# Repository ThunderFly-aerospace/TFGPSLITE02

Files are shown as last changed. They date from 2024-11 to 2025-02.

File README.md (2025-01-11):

# TFGPSLITE02 - Compact GNSS Module for Lightweight UAVs



The **TFGPSLITE02** module is a compact GNSS solution based on the [u-blox SAM-M8Q](https://www.u-blox.com/en/product/sam-m8q-module). It is designed for small, lightweight, and simple UAVs, offering excellent positioning accuracy with support for multiple satellite constellations. It connects seamlessly to flight controllers via the [Pixhawk standard "Basic GPS Port"](https://github.com/pixhawk/Pixhawk-Standards/blob/master/DS-009%20Pixhawk%20Connector%20Standard.pdf).

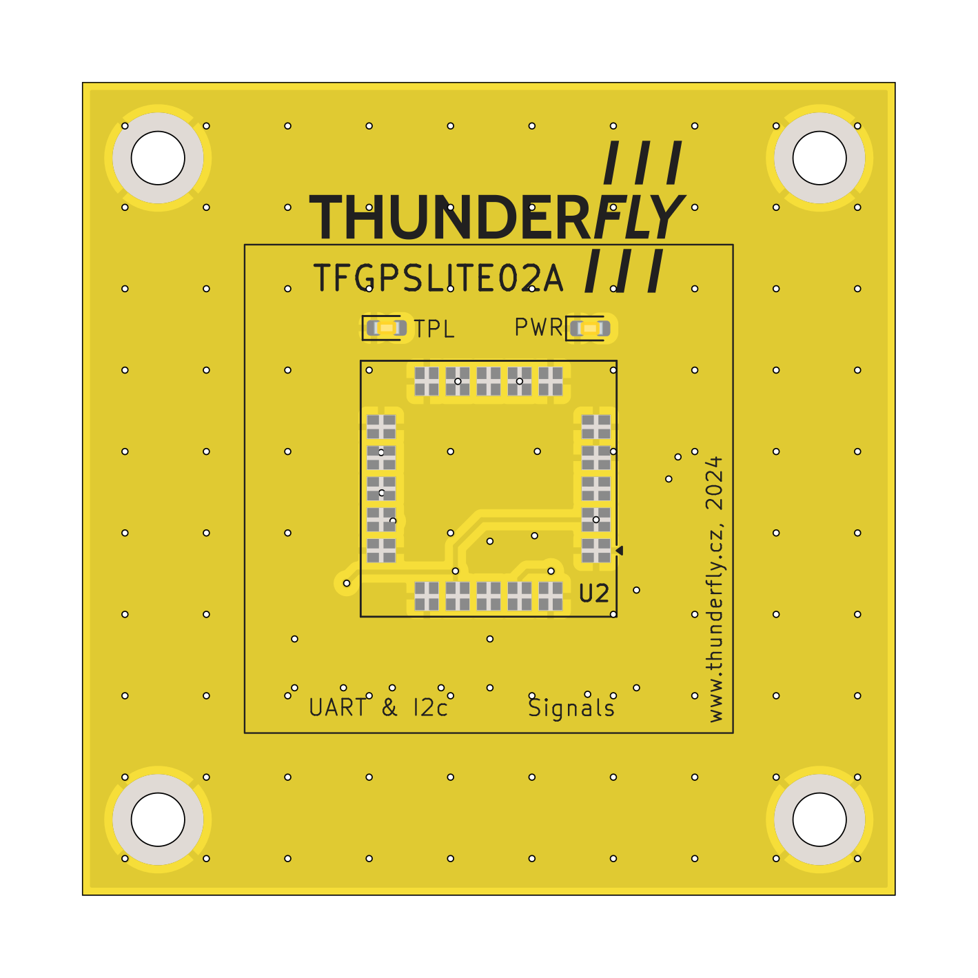
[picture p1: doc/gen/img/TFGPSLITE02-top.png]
TFGPSLITE02 top view


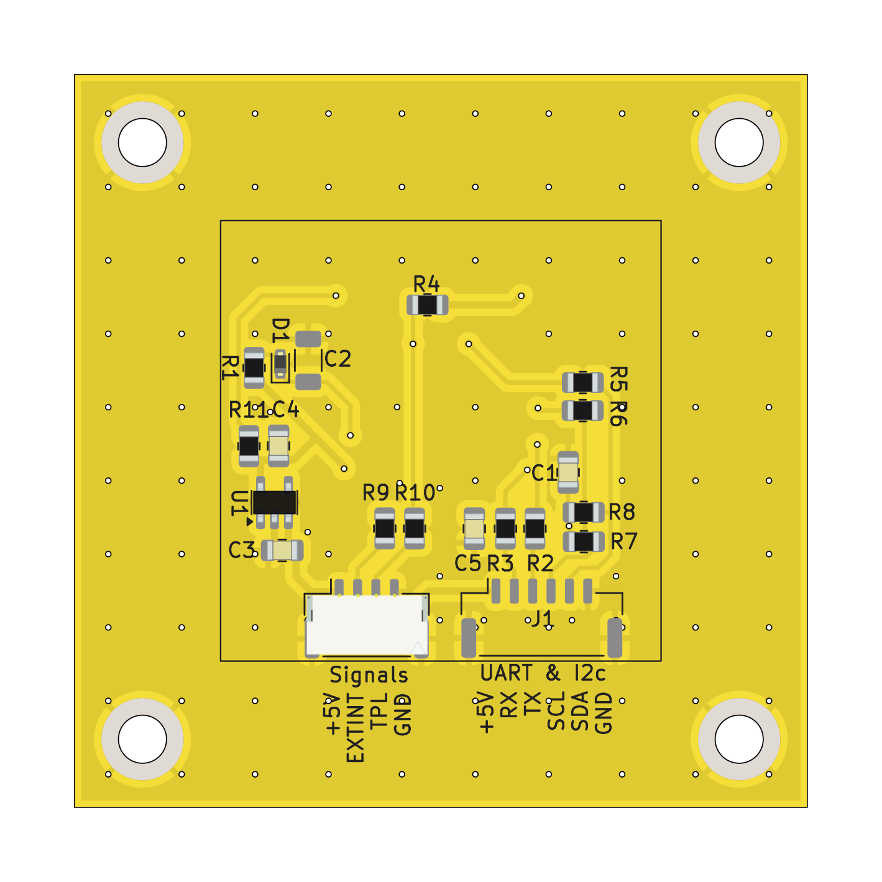
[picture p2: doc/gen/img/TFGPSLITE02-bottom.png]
TFGPSLITE02 bottom view


## Features

- **GNSS Support**: Concurrent reception of up to three GNSS systems (GPS, Galileo, GLONASS).
- **Compact Design**: Compact flat form factor with integrated patch antenna.
- **High Sensitivity**: Superior performance in environments with weak or obstructed GNSS signals.
- **Augmentation Systems**: Support for SBAS (WAAS, EGNOS, MSAS, GAGAN) and QZSS.
- **Advanced Security**:
  - Geofencing for operational boundaries.
  - Spoofing detection to enhance signal integrity.
  - Message integrity protection.
- **Wide Operational Range**:
  - Altitude: Up to 50,000 m.
  - Velocity: Up to 500 m/s.
  - Dynamic tolerance: Up to 4 g.
- **Built-in RTC**: Ensures faster Time-To-First-Fix (TTFF) after prolonged power-off periods.

## Technical Specifications

- **Interfaces**:
  - UART and I2C (via Basic GPS Port).
  - Time pulse output (1 PPS, configurable up to 10 MHz).
- **Power Supply**:
  - Main supply voltage: 5 V.
  - Typical current consumption is 30 mA.
- **GNSS Performance**:
  - Cold start TTFF: 26 s (GPS).
  - Hot start TTFF: 1 s.
  - Horizontal position accuracy: 2.5 m CEP.
- **Environmental Tolerances**:
  - Operating temperature: -40 °C to 85 °C.
  - Storage temperature: -40 °C to 85 °C.
- **Physical properties**: 
  - Dimensions 50x50x8mm
  - Weight 11.3 grams

## Connection to Flight Controller

The module interfaces with flight controllers using the Pixhawk standard **Basic GPS Port**. The port pinout is as follows:

| Pin | Signal | Voltage |
|-----|---|---|
| 1 | VCC | +5V |
| 2 | TX (OUT)  | +3.3V |
| 3 | RX (IN) | +3.3V |
| 4 | I2C SCL | +3.3V |
| 5 | I2C SDA | +3.3V |
| 6 | GND | GND |

## Connection to payload

The module interfaces with the payload with the following signals:

| Pin | Signal | Voltage |
|-----|---|---|
| 1 | VCC | +5V |
| 2 | EXTINT (IN)  | +3.3V |
| 3 | TPL (OUT) | +3.3V |
| 4 | GND | GND |

## Where to get it?

The TFGPSLITE02 is commercially available from [ThunderFly s.r.o.](https://www.thunderfly.cz/). For a commercial quotation, contact us by email at sale@thunderfly.cz or shop at our [Tindie store](https://www.tindie.com/stores/thunderfly/).

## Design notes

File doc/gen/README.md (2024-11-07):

# PCB

Board size: 50.0x50.0 mm (1.97x1.97 inches)

- This is the size of the rectangle that contains the board
- Thickness: 1.6 mm (63 mils)
- Material: FR4
- Finish: None
- Layers: 2
- Copper thickness: 35 µm

Solder mask: TOP / BOTTOM

- Color: Green

Silk screen: TOP / BOTTOM

- Color: White

Stackup:

| Name | Type | Color | Thickness [µm]| Material | Er | Loss tan |
|---|---|---|---|---|---|---|
| F.SilkS | Top Silk Screen | | | | | |
| F.Paste | Top Solder Paste | | | | | |
| F.Mask | Top Solder Mask | | 10 | | | |
| F.Cu | copper | | 35 | | | |
| dielectric 1 | core | | 1510 | FR4 | 4.5 | 0.020 |
| B.Cu | copper | | 35 | | | |
| B.Mask | Bottom Solder Mask | | 10 | | | |
| B.Paste | Bottom Solder Paste  | | | | | |
| B.SilkS | Bottom Silk Screen | | | | | |

# Important sizes

Clearance: 0.2 mm (8 mils)

Track width: 0.3 mm (12 mils)

- By design rules: 0.0 mm (0 mils)

Drill: 0.4 mm (16 mils)

- Vias: 0.4 mm (16 mils) [Design: 0.4 mm (16 mils)]
- Pads: 3.3 mm (130 mils)
- The above values are real drill sizes, they add 0.1 mm (4 mils) to plated holes (PTH)

Via: 0.6/0.3 mm (24/12 mils)

- By design rules: 0.5/0.3 mm (20/12 mils)
- Micro via: yes [0.2/0.1 mm (8/4 mils)]
- Buried/blind via: yes
- Total: 115 (thru: 115 buried/blind: 0 micro: 0)

Outer Annular Ring: 0.1 mm (4 mils)

- By design rules: 1.15 mm (45 mils)

Eurocircuits class: 6C
- Using min drill 0.35 mm for an OAR of 0.13 mm

# General stats

Components count: (SMD/THT)

- Top: 3/0 (SMD)
- Bottom: 20/0 (SMD)

Defined tracks:

- 0.3 mm (12 mils)
- 0.5 mm (20 mils)

Used tracks:

- 0.3 mm (12 mils) (70) defined: yes
- 0.5 mm (20 mils) (34) defined: yes

Defined vias:

Used vias:

- 0.6/0.3 mm (24/12 mils) (Count: 115, Aspect: 2.7 A) defined: no

Holes (excluding vias):

- 3.2 mm (126 mils) (4)

Oval holes:

Drill tools (including vias and computing adjusts and rounding):

- 0.4 mm (16 mils) (115)
- 3.3 mm (130 mils) (4)

Solder paste stats:

Using a paste with 87.75 % alloy, that has an specific gravity for the alloy of 7.4 g/cm³
and 1.0 g/cm³ for the flux. This paste has an specific gravity of  4.15 g/cm³.

The stencil thickness is  0.12 mm.

| Side | Pads with paste | Area [mm²] | Paste [g] |
|---|---|---|---|
| Top | 84 | 36.55 | 0.18 |
| Bottom | 53 | 70.45 | 0.35 |
| Total  | 137 | 107.01 | 0.53 |

Note: this is just an approximation to the theoretical value. Margins of the solder mask and waste aren't computed.

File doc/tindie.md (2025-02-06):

# TFGPSLITE02 - Compact GNSS Module for UAVs

A lightweight GNSS module with a high-quality ground plane, ideal for UAVs, multirotors, planes, and balloons.

The TFGPSLITE02 is a compact and lightweight open-source hardware GNSS module based on the u-blox SAM-M8Q receiver. Designed for small UAVs and simple navigation applications, it offers precise positioning with support for GPS, Galileo, and GLONASS constellations.

One of its key advantages is the high-quality integrated ground plane, which enhances signal reception and reduces interference. Unlike lower-cost solutions where supporting components are placed next to the antenna, degrading signal integrity, this module employs a carefully designed layout that separates supporting circuitry. By positioning these components on the opposite side of the board, this design choice, while increasing manufacturing costs, significantly improves signal stability and accuracy—an essential factor for UAV applications where GNSS signal integrity is critical.

With seamless integration via the Pixhawk Basic GPS Port, this module is an excellent choice for developers and hobbyists looking for a simple yet effective GNSS solution.

## Open-Source & Customizable

The TFGPSLITE02 is open-source hardware, allowing engineers, developers, and UAV enthusiasts to modify, improve, and adapt the design to their specific needs. Design files, schematics, and firmware resources are publicly available in the project’s repository.

---

## Key Features
- **Multi-GNSS Support** – Receives GPS, Galileo, and GLONASS signals for increased accuracy.
- **Compact and Lightweight** – Weighing only **11.3 grams**, ideal for weight-sensitive UAV applications.
- **High-Quality Ground Plane** – Improved signal reception compared to low-cost GNSS modules.
- **Reliable Performance in Challenging Environments** – Works in areas with weak GNSS signals.
- **Support for SBAS and QZSS** – Enhances positioning accuracy.
- **Advanced Security Features**:
  - Geofencing support
  - Spoofing detection
  - Message integrity protection
- **Built-in RTC (Real-Time Clock)** – Reduces Time-To-First-Fix after power loss.
- **Wide Operating Range**:
  - Up to **50,000m altitude**, **500m/s velocity**, and **4g dynamic tolerance**.

---

## Technical Specifications
- **Receiver**: u-blox SAM-M8Q GNSS module
- **Interfaces**:
  - UART and I2C (via Pixhawk Basic GPS Port)
  - 1PPS time pulse output (configurable up to 10 MHz)
- **Power Requirements**:
  - Voltage: **5V**
  - Typical power consumption: **30mA**
- **Positioning Performance**:
  - Cold start TTFF: **26s** (GPS)
  - Hot start TTFF: **1s**
  - Accuracy: **2.5m CEP**
- **Environmental Ratings**:
  - Operating temperature: **-40°C to +85°C**
  - Storage temperature: **-40°C to +85°C**
- **Physical Dimensions**:
  - **50mm × 50mm × 8mm**
  - **Weight: 11.3g**

---

## Easy Integration with UAV Systems
The TFGPSLITE02 connects to flight controllers via the **Pixhawk Basic GPS Port**, ensuring hassle-free setup. The pinout is:

| Pin | Signal  | Voltage |
|-----|---|---|
| 1 | VCC | 5V |
| 2 | TX (OUT) | 3.3V |
| 3 | RX (IN) | 3.3V |
| 4 | I2C SCL | 3.3V |
| 5 | I2C SDA | 3.3V |
| 6 | GND | GND |

It also supports external payload connections for additional signals.

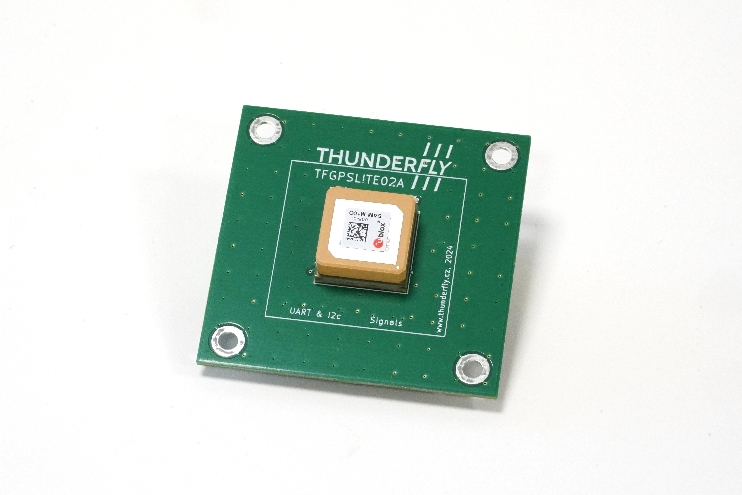
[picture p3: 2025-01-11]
doc/img/TFGPSLITE02_top.jpg

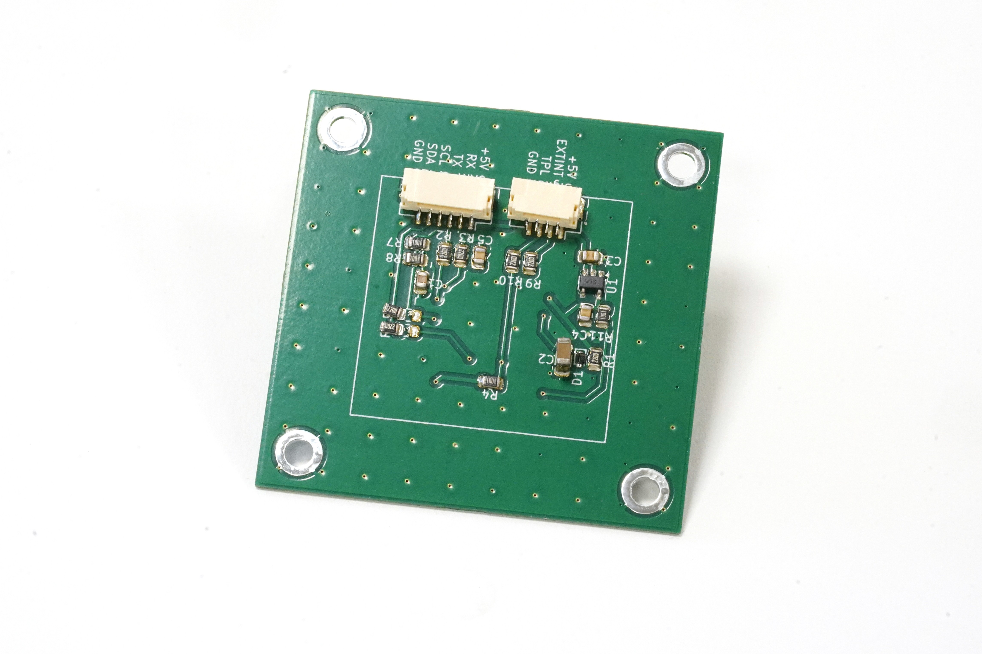
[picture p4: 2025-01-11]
doc/img/TFGPSLITE02_bot.jpg

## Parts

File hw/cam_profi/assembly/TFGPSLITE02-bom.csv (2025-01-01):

Component | Description | Part | References | Value | Footprint | Quantity Per PCB | Datasheet | ust_id | sim.device | sim.pins
1 | Unpolarized capacitor, small symbol | C_Small | C3C4C5 | 100n | C_0805_2012Metric | 3 | ~ | 5c70984812875079b91f8bf2
2 | Unpolarized capacitor, small symbol | C_Small | C1 | 1u | C_0805_2012Metric | 1 | ~ | 5c70984812875079b91f8bc3
3 | Unpolarized capacitor | C | C2 | C | R_1206_3216Metric | 1 | ~
4 | Diode, small symbol | D_Small | D1 | BZX585-B5V6.115 | D_SOD-523 | 1 | ~ |  | D | 1=K 2=A
5 | Light emitting diode, small symbol | LED_Small | D3 | GREEN | LED_0603_1608Metric | 1 | ~ | 60d582331287500165f859d0
6 | Light emitting diode, small symbol | LED_Small | D2 | RED | LED_0603_1608Metric | 1 | ~ | 60d582331287500165f859d0
7 |  | SM04B-GHS-TB | J2 | SM04B-GHS-TB | JST_GH_SM04B-GHS-TB_1x04-1MP_P1.25mm_Horizontal | 1
8 | 1x07 2.54 mm pitch header | SM06B-GHS-TB | J1 | SM06B-GHS-TB | JST_GH_SM06B-GHS-TB_1x06-1MP_P1.25mm_Horizontal | 1
9 | Resistor, small symbol | R_Small | R2R3R5R6R9R10 | 220R | R_0805_2012Metric | 6 | ~ | 5c70984512875079b91f8958
10 | Resistor, small symbol | R_Small | R4R11 | 1k | R_0805_2012Metric | 2 | ~ | 5c70984512875079b91f895c
11 | Resistor, small symbol | R_Small | R1R7R8 | R_Small | R_0805_2012Metric | 3 | ~
12 | 300mA Low-dropout Voltage Regulator, Vout 3.3V, Vin up to 5.5V, SOT-23 | MIC5504-3.3YM5 | U1 | MIC5504-3.3YM5 | SOT-23-5 | 1 | http://ww1.microchip.com/downloads/en/DeviceDoc/MIC550X.pdf | 5c7255e81287500b4e112ea2
13 | GPS ublox M8 variant | SAM-M8Q | U2 | SAM-M8Q | ublox_SAM-M8Q | 1 | https://content.u-blox.com/sites/default/files/documents/SAM-M8Q_DataSheet_UBX-16012619.pdf

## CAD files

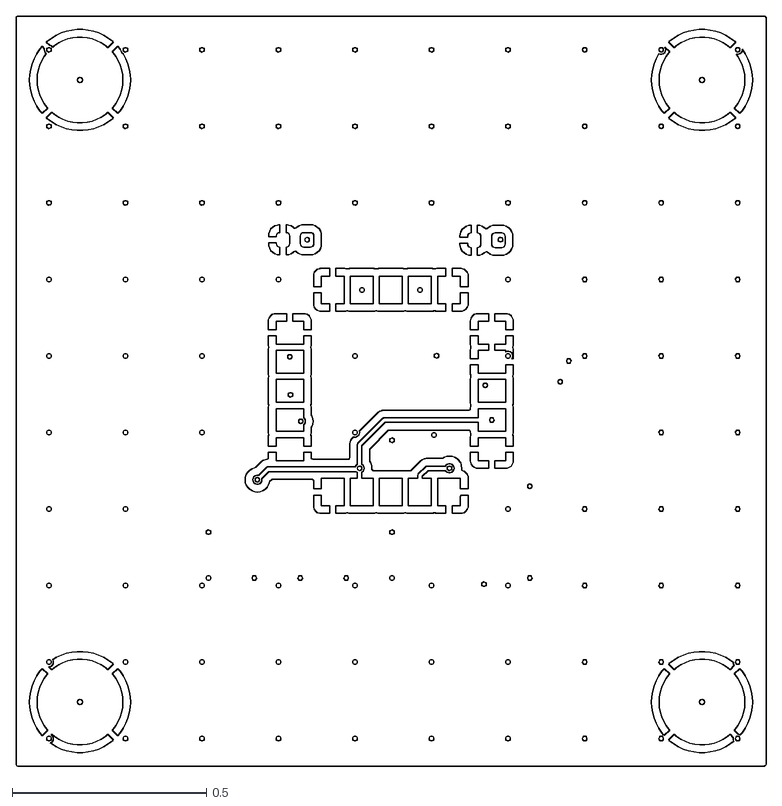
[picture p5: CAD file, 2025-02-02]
doc/gen/dxf/TFGPSLITE02-F_Cu.dxf
1.93 x 1.93

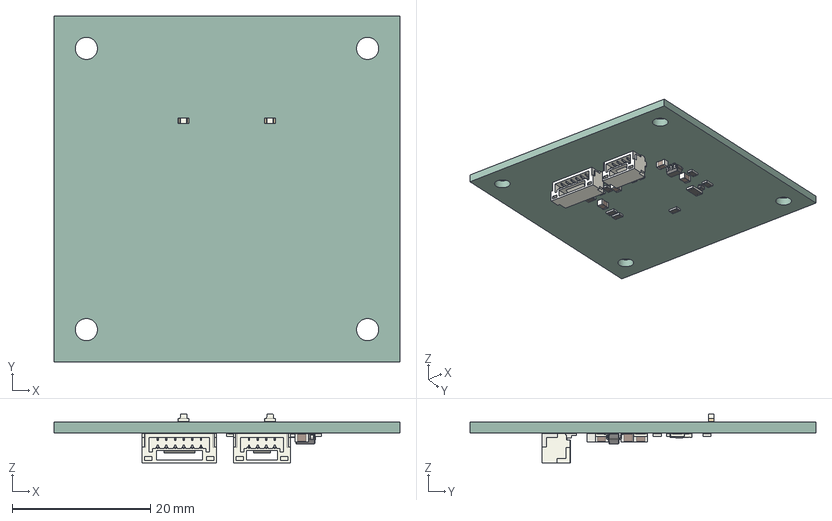
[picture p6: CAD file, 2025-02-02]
doc/gen/TFGPSLITE02.step
50.0 x 50.0 x 7.04 mm
LED_0603_1608Metric x 2
R_0805_2012Metric x 11
C_0805_2012Metric x 4
SOT_23_5
D_SOD_523
JST_SM06B_GHS_TB
JST_SM04B_GHS_TB
R_1206_3216Metric
kibot_6tp2d779_PCB

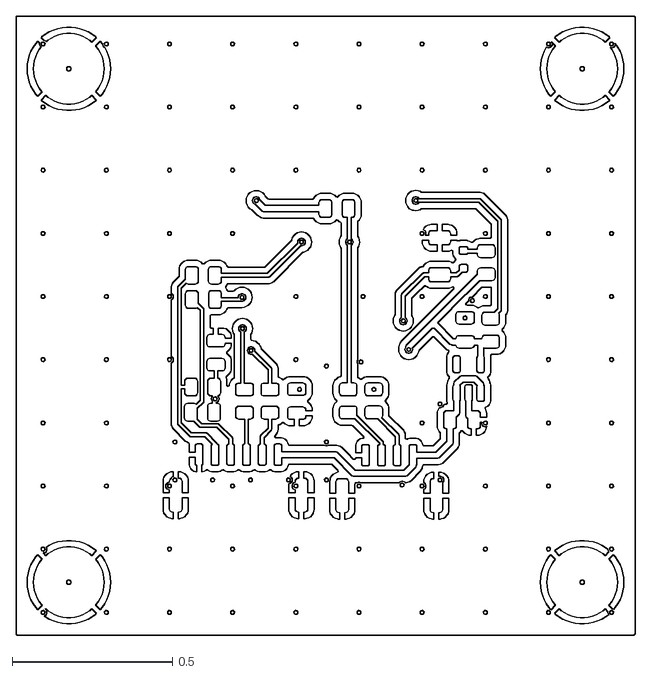
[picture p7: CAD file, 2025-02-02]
doc/gen/dxf/TFGPSLITE02-B_Cu.dxf
1.93 x 1.93

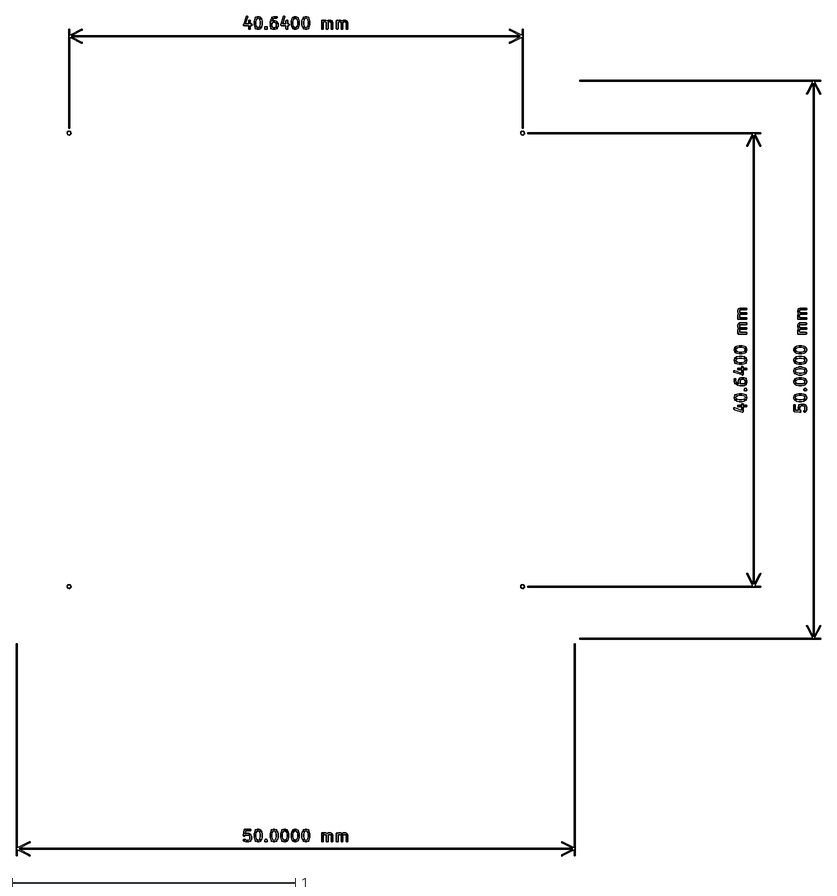
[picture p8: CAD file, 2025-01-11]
doc/gen/dxf/TFGPSLITE02-User_Drawings.dxf
2.84 x 2.96

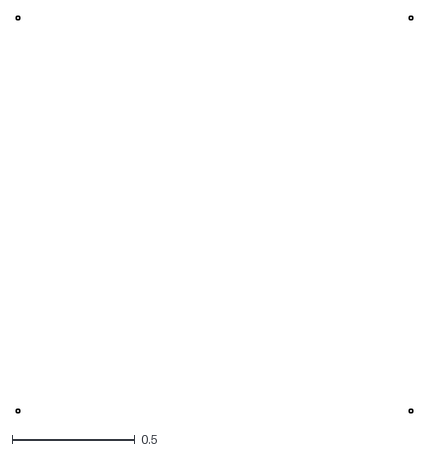
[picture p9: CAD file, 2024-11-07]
doc/gen/dxf/TFGPSLITE02-Margin.dxf
1.61 x 1.61

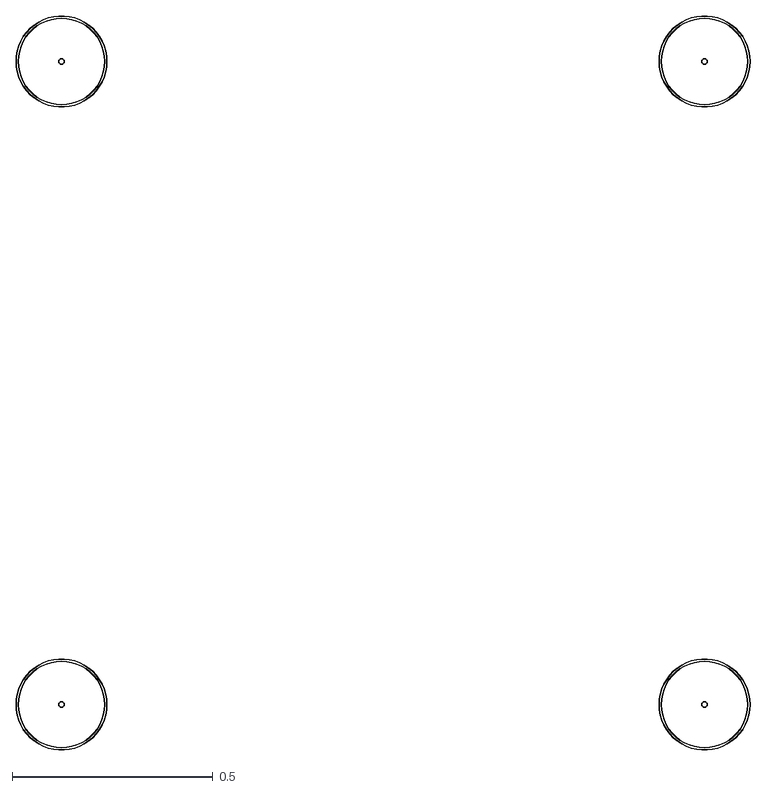
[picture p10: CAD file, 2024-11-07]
doc/gen/dxf/TFGPSLITE02-User_Comments.dxf
1.83 x 1.83

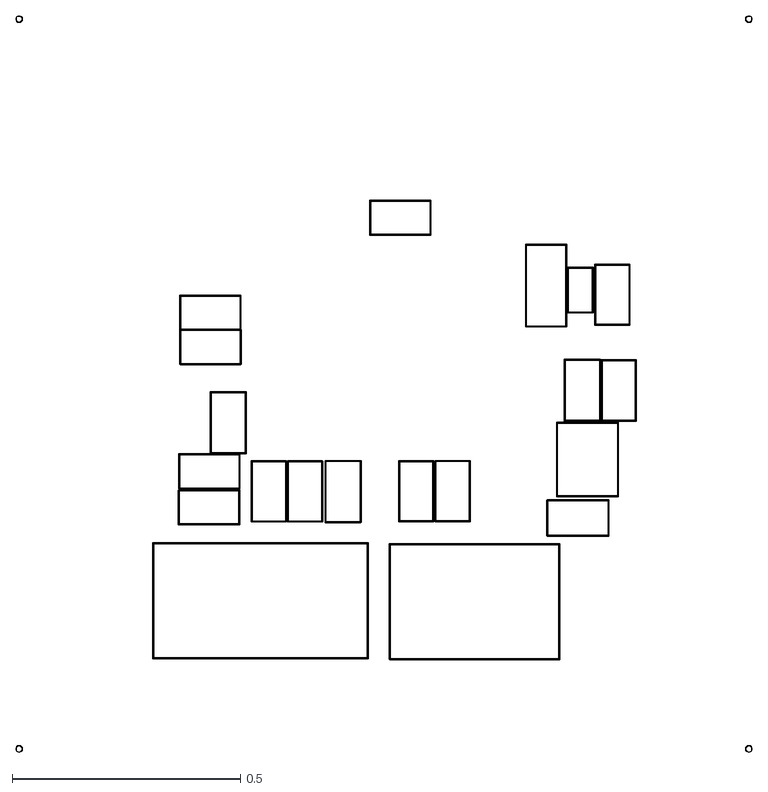
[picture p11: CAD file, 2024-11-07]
doc/gen/dxf/TFGPSLITE02-B_Courtyard.dxf
1.61 x 1.61

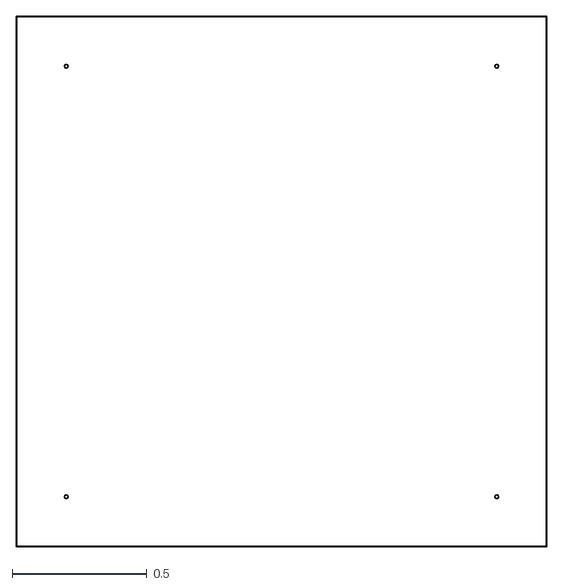
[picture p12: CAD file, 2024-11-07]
doc/gen/dxf/TFGPSLITE02-Edge_Cuts.dxf
1.97 x 1.97

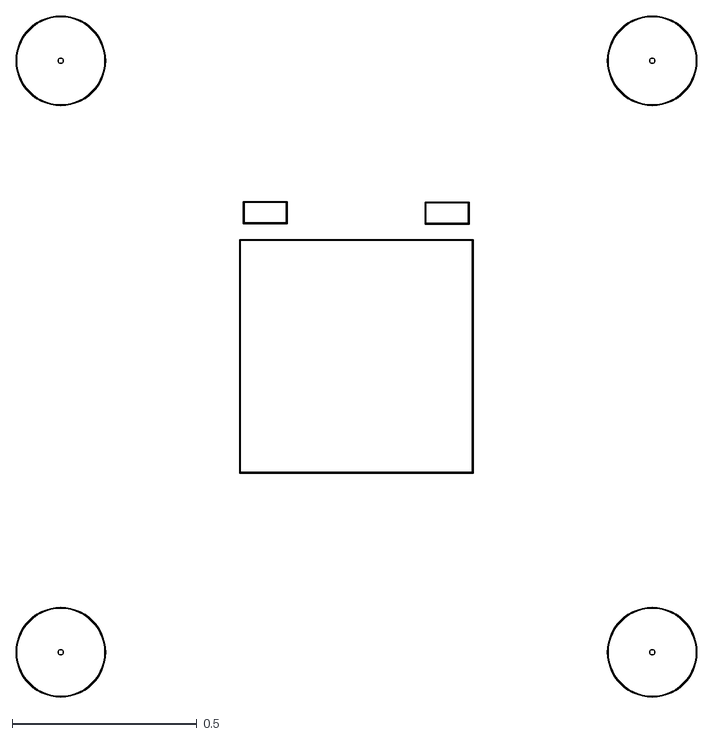
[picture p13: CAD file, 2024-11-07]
doc/gen/dxf/TFGPSLITE02-F_Courtyard.dxf
1.84 x 1.84

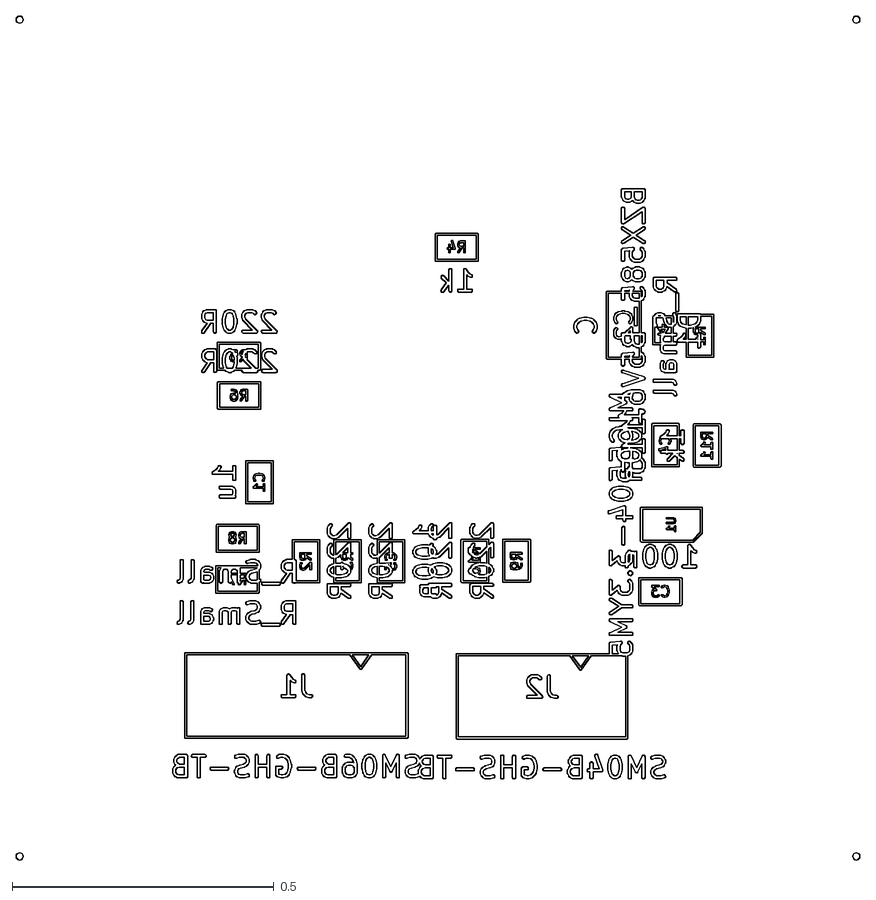
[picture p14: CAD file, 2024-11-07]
doc/gen/dxf/TFGPSLITE02-B_Fab.dxf
1.61 x 1.61

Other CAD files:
doc/gen/dxf/TFGPSLITE02-B_Adhesive.dxf
doc/gen/dxf/TFGPSLITE02-B_Mask.dxf
doc/gen/dxf/TFGPSLITE02-B_Paste.dxf
doc/gen/dxf/TFGPSLITE02-B_Silkscreen.dxf
doc/gen/dxf/TFGPSLITE02-F_Adhesive.dxf
doc/gen/dxf/TFGPSLITE02-F_Fab.dxf
doc/gen/dxf/TFGPSLITE02-F_Mask.dxf
doc/gen/dxf/TFGPSLITE02-F_Paste.dxf
doc/gen/dxf/TFGPSLITE02-F_Silkscreen.dxf

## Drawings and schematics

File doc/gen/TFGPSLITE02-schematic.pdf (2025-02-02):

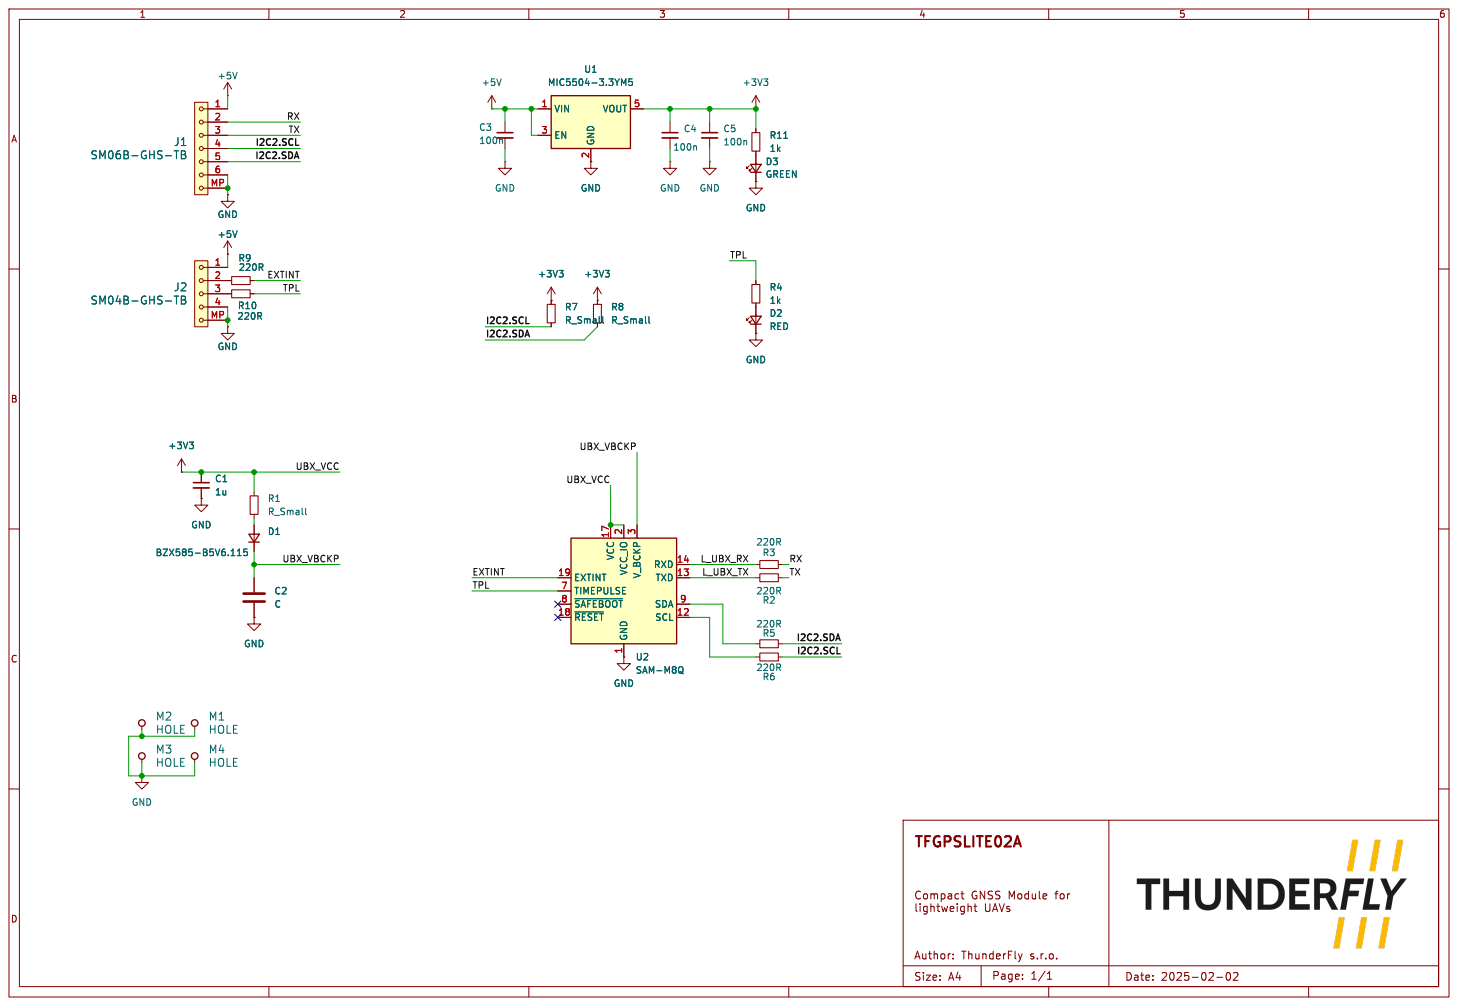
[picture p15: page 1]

3 TIMEPULSE 7 ~{SAFEBOOT} 8 SDA 9 R7 R_Small R8 R_Small D2 RED GND

1 SCL 12 TXD 13 RXD VCC 14 17

Compact GNSS Module for

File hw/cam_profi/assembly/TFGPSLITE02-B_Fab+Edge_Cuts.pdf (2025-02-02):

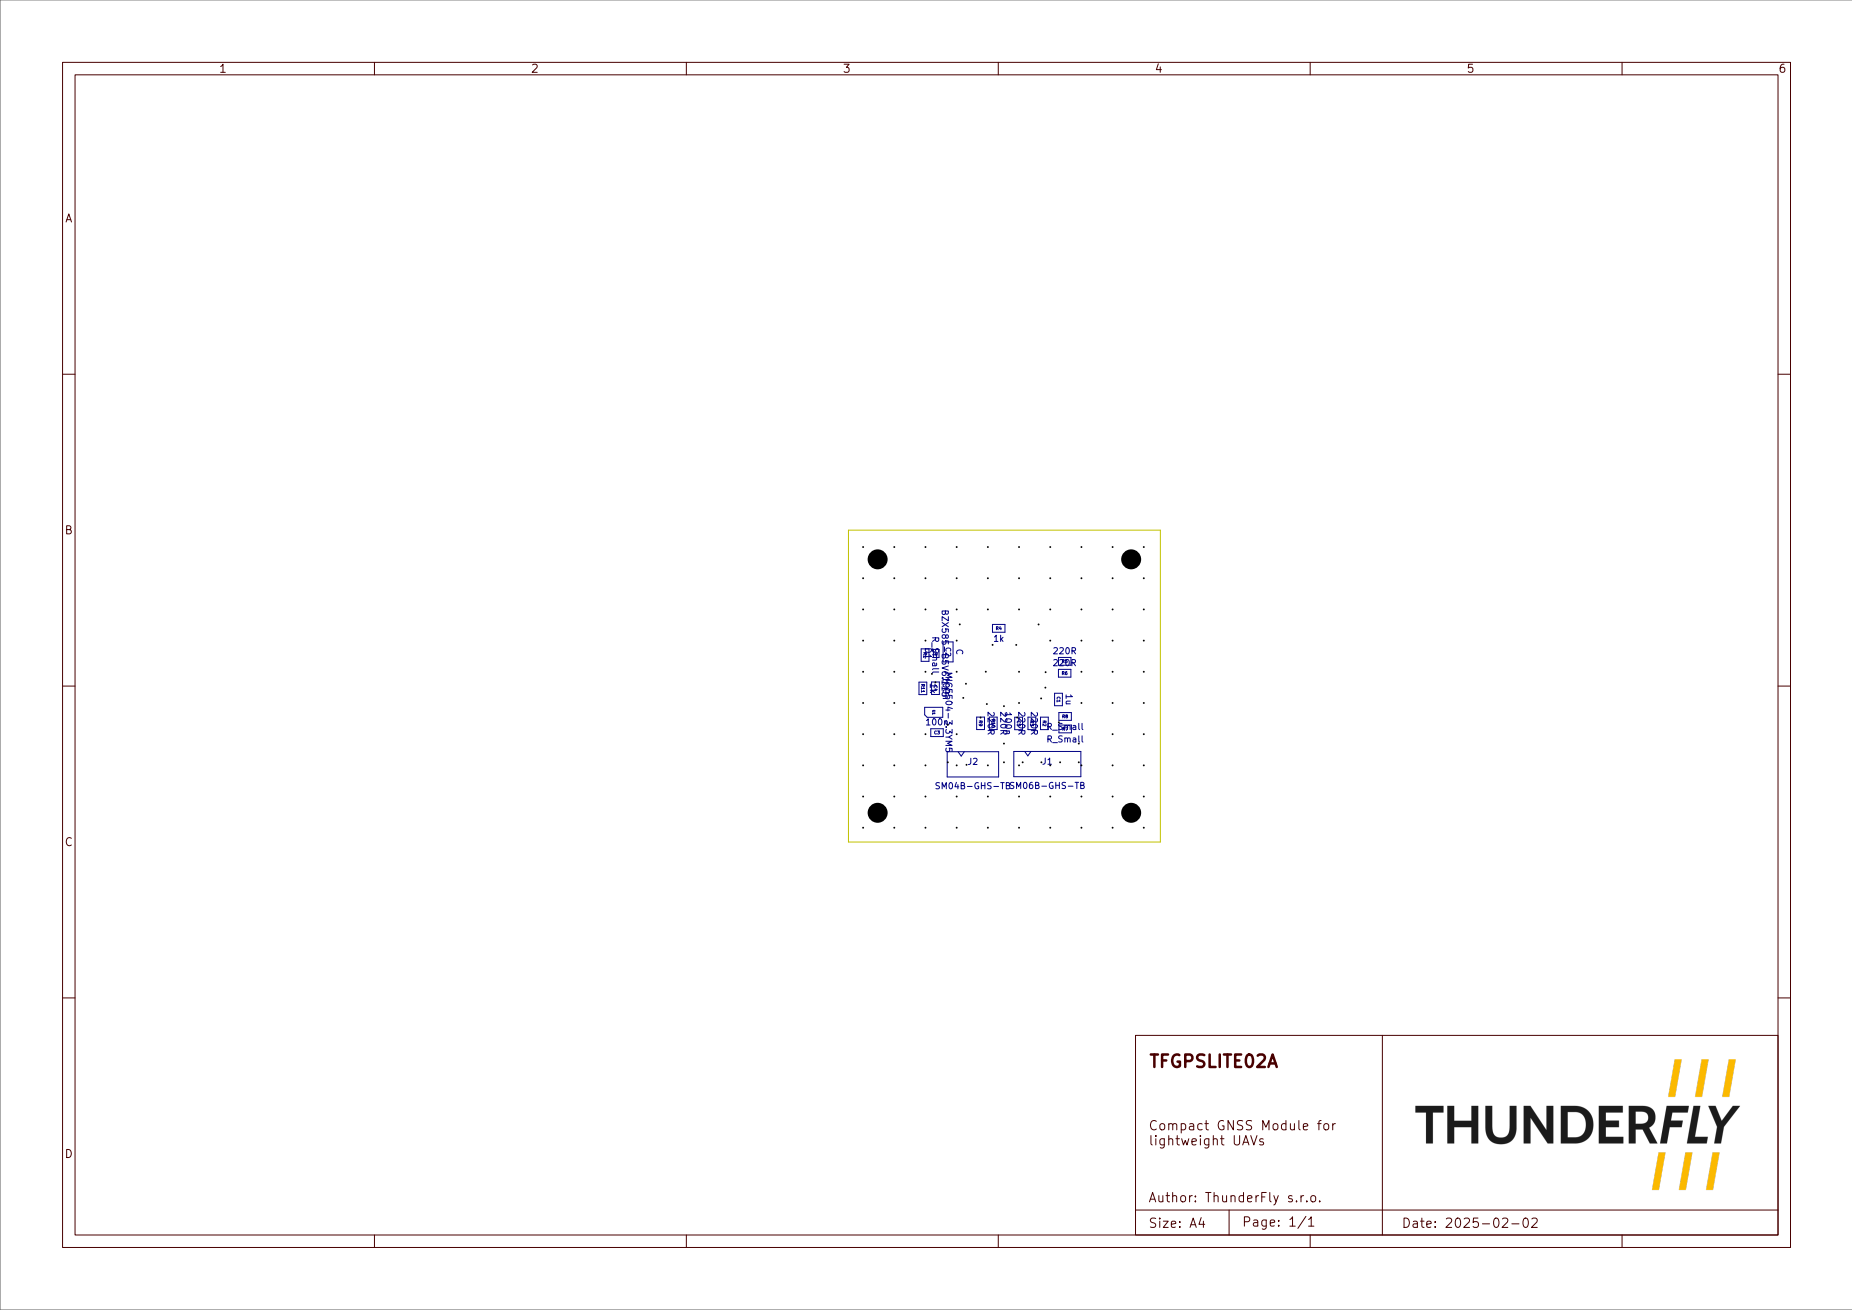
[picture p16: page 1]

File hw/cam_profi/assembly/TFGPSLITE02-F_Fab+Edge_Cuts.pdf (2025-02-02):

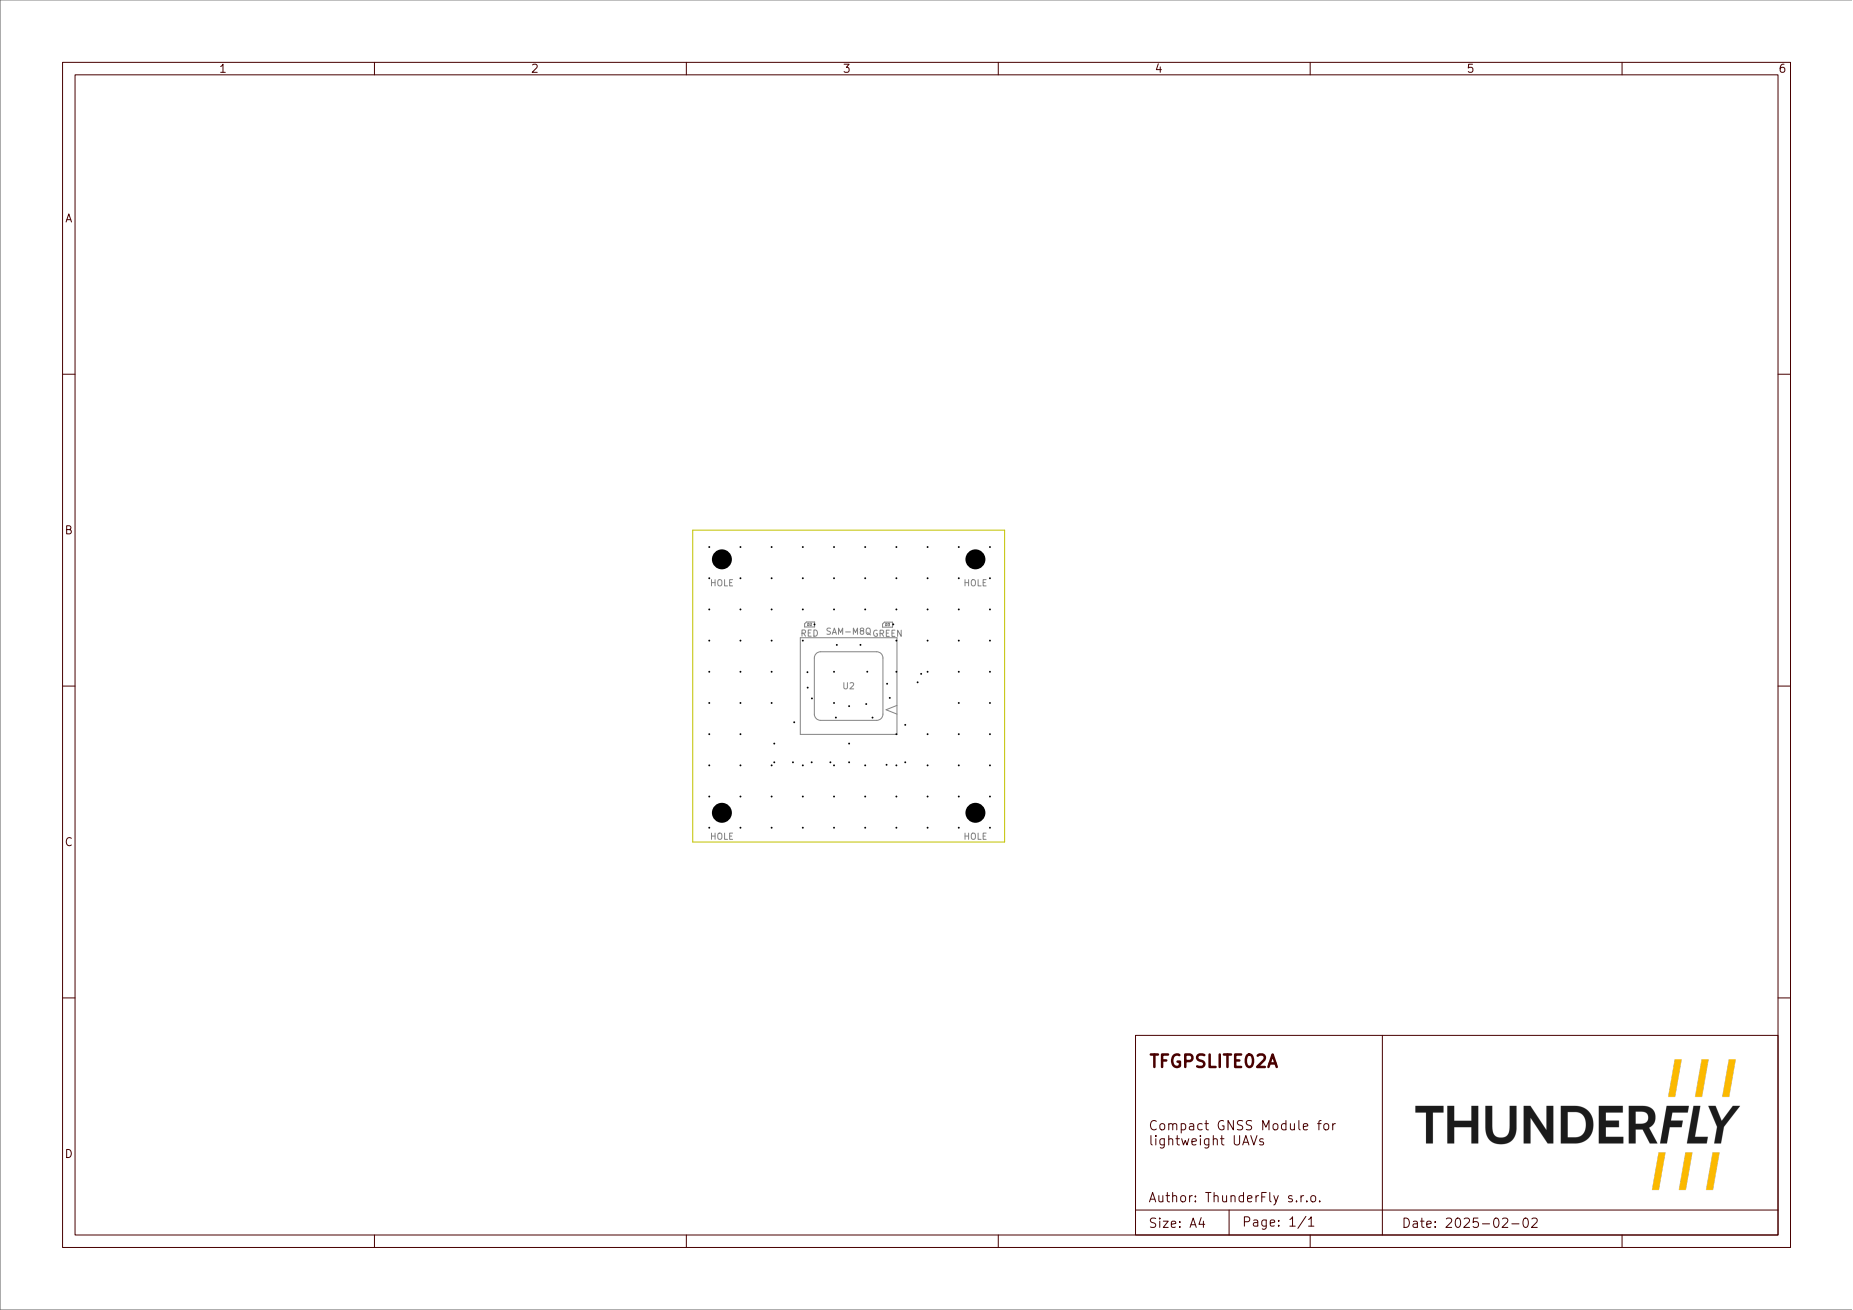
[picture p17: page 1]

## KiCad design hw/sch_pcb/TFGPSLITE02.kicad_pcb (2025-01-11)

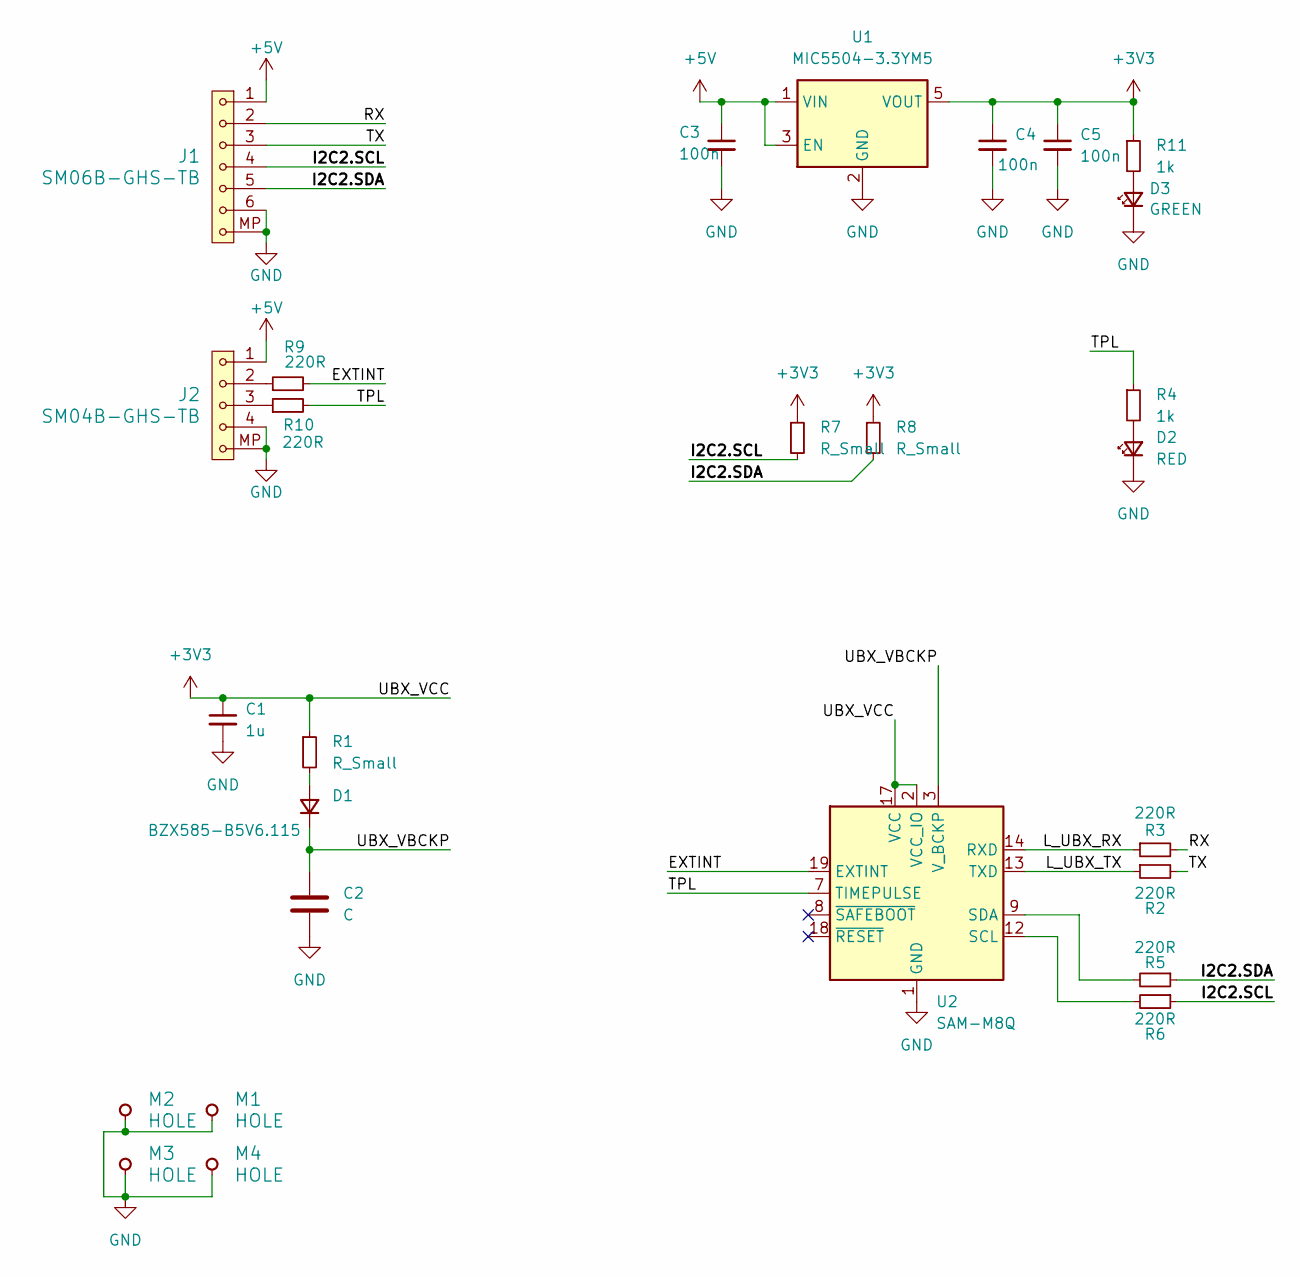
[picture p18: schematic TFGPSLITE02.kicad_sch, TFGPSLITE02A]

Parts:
C1: 1u; C_0805_2012Metric
C2: C; R_1206_3216Metric
C3, C4, C5: 100n; C_0805_2012Metric
D1: BZX585-B5V6.115; D_SOD-523
D2: RED; LED_0603_1608Metric
D3: GREEN; LED_0603_1608Metric
J1: SM06B-GHS-TB; JST_GH_SM06B-GHS-TB_1x06-1MP_P1.25mm_Horizontal
J2: SM04B-GHS-TB; JST_GH_SM04B-GHS-TB_1x04-1MP_P1.25mm_Horizontal
M1, M2, M3, M4: HOLE; MountingHole_3.2mm_M3_DIN965_Pad
R1, R7, R8: R_Small; R_0805_2012Metric
R2, R3, R5, R6, R9, R10: 220R; R_0805_2012Metric
R4, R11: 1k; R_0805_2012Metric
U1: MIC5504-3.3YM5; SOT-23-5
U2: SAM-M8Q; ublox_SAM-M8Q

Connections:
+3V3: C1.1, C4.1, C5.1, R1.1, R7.1, R8.1, R11.1, U1.5 (VOUT), U2.2 (VCC_IO), U2.17 (VCC)
+5V: C3.1, J1.1, J2.1, U1.1 (VIN), U1.3 (EN)
/EXTINT: R9.2, U2.19 (EXTINT)
/I2C2.SCL: J1.4, R6.1, R7.2
/I2C2.SDA: J1.5, R5.1, R8.2
/L_UBX_RX: R3.1, U2.14 (RXD)
/L_UBX_TX: R2.1, U2.13 (TXD)
/RX: J1.2, R3.2
/TPL: R4.1, R10.2, U2.7 (TIMEPULSE)
/TX: J1.3, R2.2
/UBX_VBCKP: C2.1, D1.1 (K), U2.3 (V_BCKP)
GND: C1.2, C2.2, C3.2, C4.2, C5.2, D2.1 (K), D3.1 (K), J1.6, J1.MP, J2.4, J2.MP, M1.1, M2.1, M3.1, M4.1, U1.2 (GND), U2.1 (GND), U2.4 (GND), U2.5 (GND), U2.6 (GND), U2.10 (GND), U2.11 (GND), U2.15 (GND), U2.16 (GND), U2.20 (GND)
unnamed: D1.2 (A), R1.2
unnamed: D2.2 (A), R4.2
unnamed: D3.2 (A), R11.2
unnamed: J2.2, R9.1
unnamed: J2.3, R10.1
unnamed: R6.2, U2.12 (SCL)
unnamed: R5.2, U2.9 (SDA)

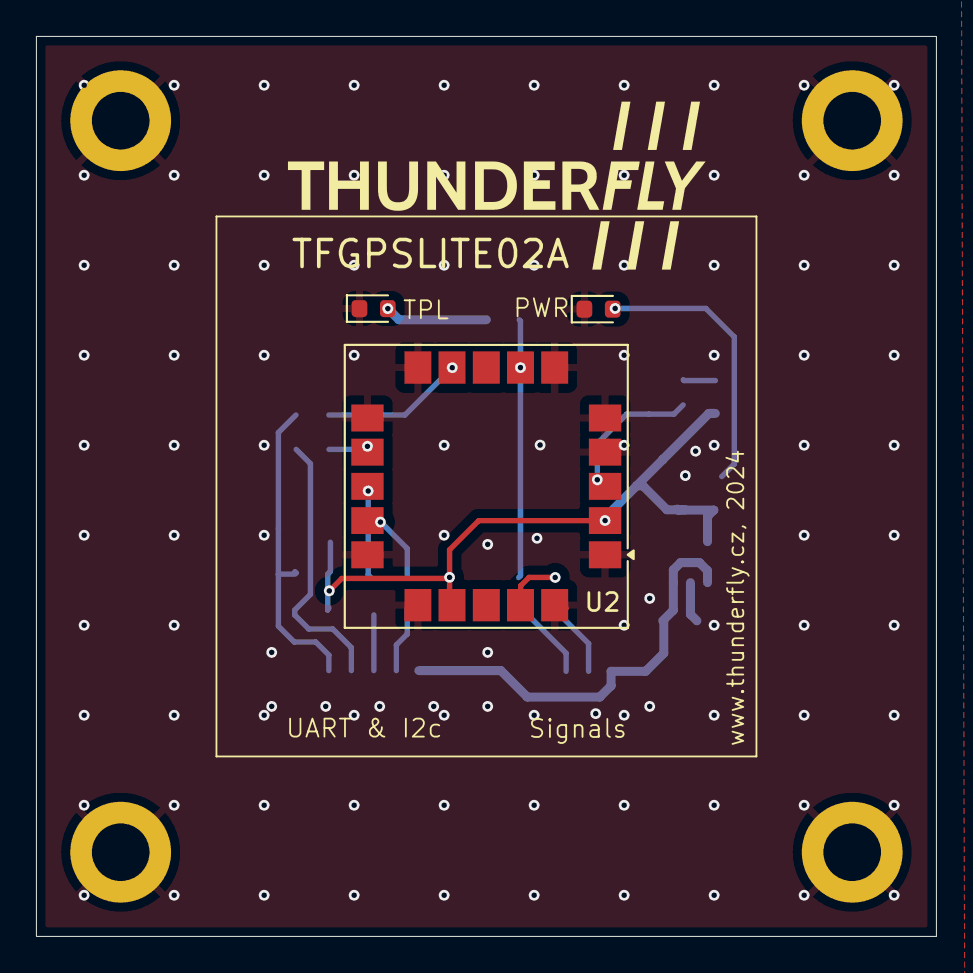
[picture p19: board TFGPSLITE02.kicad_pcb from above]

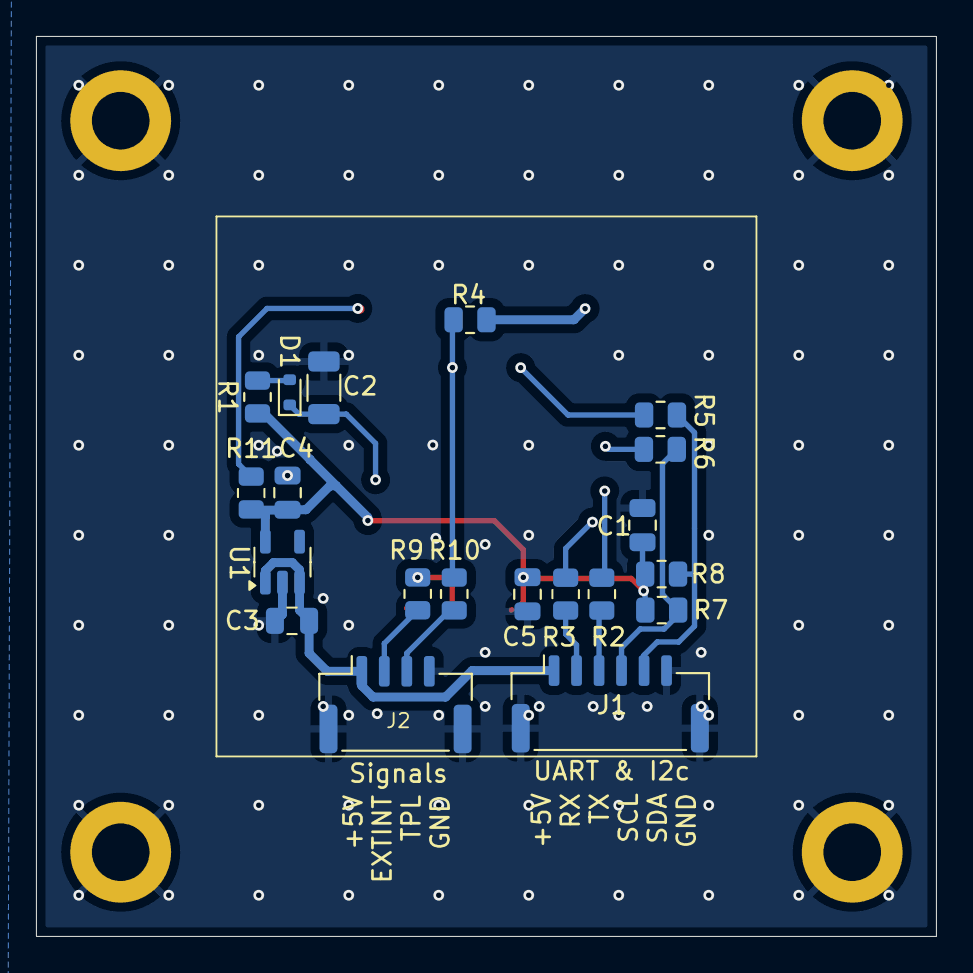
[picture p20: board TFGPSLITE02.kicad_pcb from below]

Board: 2 copper layers, 50.0 x 50.0 mm, 27 parts (20 on the bottom side), 19 nets.

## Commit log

2024-10-13 update assets, initial commit of kicad files
    [TFGPSLITE01.kicad_pcb, TFGPSLITE01.kicad_sch]
2024-10-14 solve DRC, silkscreen
    [TFGPSLITE01.kicad_pcb, TFGPSLITE01.kicad_sch]
2024-10-18 update actions
    [TFGPSLITE01.kicad_pcb]
2024-10-18 Update actions products
    [TFGPSLITE01-B_Adhesive.dxf, TFGPSLITE01-B_Courtyard.dxf, TFGPSLITE01-B_Cu.dxf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]
2024-11-07 Design of TFGPSLITE01
    [TFGPSLITE01.kicad_pcb, TFGPSLITE02.kicad_pcb, TFGPSLITE02.kicad_sch]
2024-11-07 improve layout
    [TFGPSLITE02.kicad_pcb, TFGPSLITE02.kicad_sch]
2025-01-01 Improve documentation.
    [TFGPSLITE02.kicad_sch]
2025-01-11 Update schematics and PCB title blocks.
    [TFGPSLITE02.kicad_pcb, TFGPSLITE02.kicad_sch]
